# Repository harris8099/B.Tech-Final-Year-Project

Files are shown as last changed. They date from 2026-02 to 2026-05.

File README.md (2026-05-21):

# ESP32 Smart Motor Monitor — PCB Design

> KiCad schematic and PCB layout for an ESP32-based industrial motor monitoring and protection system.

---

## Quick Links

| Resource | Link |
|---|---|
| 🌐 Live cloud dashboard | [motor-frontend-psi.vercel.app](https://motor-frontend-psi.vercel.app/) |
| 🖥️ ESP32 local website (demo) | [harris8099.github.io/Motor-Website](https://harris8099.github.io/Motor-Website/index.html) |
| 📦 ESP32 firmware (this repo) | [github.com/harris8099/Final-Year-Project](https://github.com/harris8099/Final-Year-Project) |
| 🎓 PCB schematic and layout | [github.com/harris8099/B.Tech-Final-Year-Project](https://github.com/harris8099/B.Tech-Final-Year-Project) |
| 🖼️ Frontend repository | [github.com/harris8099/Motor-frontend](https://github.com/harris8099/Motor-frontend) |
| ⚙️ Backend repository | [github.com/harris8099/Motor-backend](https://github.com/harris8099/Motor-backend) |
| 📐 Project diagrams & architecture | [github.com/harris8099/Motor-project-Diagram](https://github.com/harris8099/Motor-project-Diagram) |
| 📱 Alternative Bluetooth approach | [harris8099.github.io/Bluetooth-Motor-app](https://harris8099.github.io/Bluetooth-Motor-app/) |

---

## Schematic Overview

Motor Connector Pinout
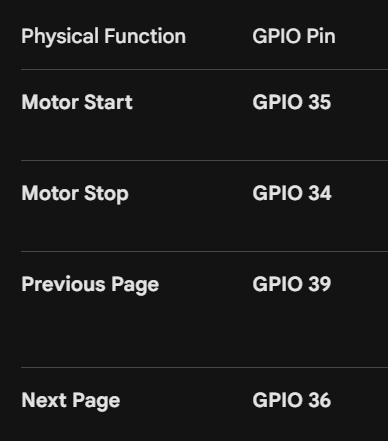
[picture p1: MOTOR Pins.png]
Motor Connector Pinout


ADXL345 Sensitivity Reference
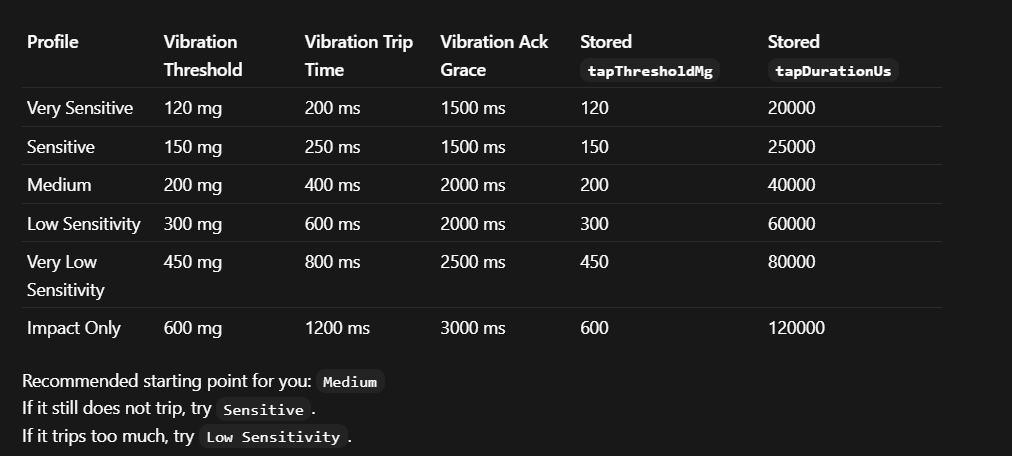
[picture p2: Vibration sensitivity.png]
ADXL345 Sensitivity


## Project Files

| File | Description |
|---|---|
| `ESP32_Smart_Motor_Project.kicad_sch` | Main schematic |
| `overall.kicad_sch` | Top-level/hierarchical schematic |
| `ESP32_Smart_Motor_Project.kicad_pcb` | PCB layout |
| `ESP32_Smart_Motor_Project.kicad_pro` | KiCad project file |
| `Symbol_Lib.kicad_sym` | Custom component symbol library |
| `sch.pdf` | Schematic PDF export |
| `Components_Links.xlsx` | Full BOM with supplier links |
| `ESP32.jpg` | ESP32 module reference image |
| `MOTOR Pins.png` | Motor connector pinout reference |
| `Vibration sensitivity.png` | ADXL345 sensitivity reference |
| `pcbway_production/` | Gerber files for PCB fabrication (PCBWay) |
| `plots/` | Schematic and layout plot exports |
| `Datasheet/` | Component datasheets |

---

## Schematic Overview

The schematic is divided into functional blocks:

### 1. Microcontroller — ESP32-WROOM-32
- Dual-core Xtensa LX6 @ 240 MHz
- 4MB Flash, 520KB SRAM
- On-board Wi-Fi 802.11 b/g/n
- USB-to-UART via CP2102/CH340 for programming and debug
- 3.3V operation with on-board LDO

### 2. Power Supply
- Input: 5V DC from external adapter or USB
- ESP32 powered via 3.3V LDO (AMS1117-3.3 or equivalent)
- Decoupling capacitors on all supply rails (100nF ceramic + 10µF electrolytic)
- Separate power domains for analog sensors and digital logic

### 3. PZEM-004T v3.0 — Power Measurement
- Interface: UART2 (TX → GPIO17, RX → GPIO16)
- Measures: Voltage (80–260V AC), Current (0–100A), Active Power, Energy (kWh), Frequency, Power Factor
- CT (current transformer) clamp around motor live wire
- Isolated from ESP32 logic via UART optocoupler or direct UART (module has internal isolation)
- Baud rate: 9600, 8N1

### 4. DS18B20 — Temperature Sensor
- Interface: 1-Wire (single GPIO)
- 4.7kΩ pull-up resistor on data line to 3.3V (**required**)
- Measures motor winding temperature: –55°C to +125°C, ±0.5°C accuracy
- Waterproof probe variant recommended for motor surface mounting

### 5. ADXL345 — Vibration / Acceleration Sensor
- Interface: I2C (SDA, SCL)
- I2C address: 0x53 (SDO pulled low) or 0x1D (SDO high)
- 4.7kΩ pull-up resistors on SDA and SCL lines
- Range: ±16g, Resolution: 3.9mg/LSB at full range
- Tap detection configured via firmware (threshold, duration, axes)
- Decoupling: 100nF on VCC pin

### 6. Hall Effect Sensor — RPM Measurement
- Interface: GPIO (interrupt-driven)
- GPIO5 configured as input with interrupt on rising edge
- Magnet mounted on motor shaft; sensor detects each revolution
- Pull-up resistor on signal line
- 100nF ceramic capacitor from signal to GND for EMI suppression

### 7. Relay Module — Motor Contactor
- Interface: GPIO (active-low)
- Drives motor contactor coil via relay
- Flyback diode (1N4007) across relay coil for back-EMF protection
- Optocoupler isolation between ESP32 logic and relay coil circuit
- LED indicator for relay state

### 8. Buzzer — Fault Alert
- Interface: GPIO (PWM capable)
- Active buzzer driven via NPN transistor (BC547 or 2N2222)
- 1kΩ base resistor, 10kΩ pull-down to prevent ghost triggering at boot
- Sounds on fault latch

### 9. TFT Display
- Interface: SPI
- CS, DC, RST, BLK connected to dedicated GPIOs
- Backlight PWM dimming capable
- Displays real-time sensor values and fault status locally

---

## Pin Assignment

| GPIO | Function | Direction | Notes |
|---|---|---|---|
| GPIO5 | Hall sensor | Input (IRQ) | 100nF cap to GND |
| GPIO16 | PZEM004T RX | Input | UART2 |
| GPIO17 | PZEM004T TX | Output | UART2 |
| GPIO21 | I2C SDA | Bidirectional | 4.7kΩ pull-up |
| GPIO22 | I2C SCL | Output | 4.7kΩ pull-up |
| GPIO26 | Relay | Output | Active-low |
| GPIO27 | Buzzer | Output | Via NPN transistor |
| 1-Wire GPIO | DS18B20 | Bidirectional | 4.7kΩ pull-up |
| SPI GPIOs | TFT Display | Output | CS/DC/RST/BLK |
| GPIO36 | TFT Button | Input | menu_next (ADC capable) |
| EN / IO0 | Boot control | — | Boot strapping pins |

---

## PCB Design Notes

### Layer Stack
- **2-layer PCB** (standard FR4, 1.6mm thickness)
- Top layer: signal routing + components
- Bottom layer: ground plane + power traces

### Design Rules
- Minimum trace width: 0.25mm (signal), 1.0mm (power), 2.0mm (5V/relay)
- Minimum clearance: 0.2mm
- Via drill: 0.8mm, via pad: 1.6mm
- Board outline: defined in Edge.Cuts layer

### Layout Guidelines Applied
- ESP32 module antenna area kept clear of copper pours and traces
- PZEM UART traces kept short and away from relay switching traces
- I2C pull-up resistors placed close to SDA/SCL pins
- DS18B20 pull-up resistor placed close to connector
- Relay and motor-side traces physically separated from ESP32 signal area
- Decoupling capacitors placed as close as possible to IC power pins
- Ground plane on bottom layer with stitching vias

### Production Files (pcbway_production/)
Standard Gerber outputs for PCBWay fabrication:
- `*.GTL` — Top copper
- `*.GBL` — Bottom copper
- `*.GTS` — Top solder mask
- `*.GBS` — Bottom solder mask
- `*.GTO` — Top silkscreen
- `*.GBO` — Bottom silkscreen
- `*.GKO` — Board outline
- `*.DRL` — Drill file (Excellon)

---

## Bill of Materials (BOM)

Full BOM with supplier links is in `Components_Links.xlsx`. Key components:

| Ref | Component | Value / Part | Package |
|---|---|---|---|
| U1 | ESP32-WROOM-32 | ESP32-WROOM-32D | Module |
| U2 | PZEM-004T | v3.0 | Module |
| U3 | ADXL345 | ADXL345BCCZ | LGA-14 |
| U4 | DS18B20 | DS18B20 | TO-92 / Probe |
| U5 | Voltage Regulator | AMS1117-3.3 | SOT-223 |
| Q1 | NPN Transistor | BC547 / 2N2222 | TO-92 |
| RL1 | Relay | 5V SPDT 10A | Through-hole |
| D1 | Flyback Diode | 1N4007 | DO-41 |
| R1 | DS18B20 Pull-up | 4.7kΩ | 0402 |
| R2, R3 | I2C Pull-up | 4.7kΩ | 0402 |
| R4 | Buzzer Base | 1kΩ | 0402 |
| R5 | Buzzer Pull-down | 10kΩ | 0402 |
| R6 | Hall Pull-up | 10kΩ | 0402 |
| C1–C5 | Decoupling | 100nF | 0402 |
| C6, C7 | Bulk Decoupling | 10µF | 0805 |
| BZ1 | Buzzer | Active 5V | Through-hole |
| J1 | Motor Connector | Screw terminal 3P | 5.08mm pitch |
| J2 | PZEM Connector | JST/Screw 4P | — |
| J3 | TFT Connector | Pin header 8P | 2.54mm |
| J4 | USB / Power | Micro-USB / DC jack | — |
| HALL1 | Hall Sensor | SS49E / A3144 | TO-92 |
| TFT1 | TFT Display | ST7789 / ILI9341 | Module |

---

## Schematic PDF

See [`sch.pdf`](sch.pdf) for the full schematic with all net labels, component values, and reference designators.

---

## Tools Used

| Tool | Version | Purpose |
|---|---|---|
| KiCad | 7.x / 8.x | Schematic capture + PCB layout |
| PCBWay | — | PCB fabrication |
| KiCad PDF Plotter | — | `sch.pdf` export |

---

## Related Repositories

| Repository | Description |
|---|---|
| [Final-Year-Project](https://github.com/harris8099/Final-Year-Project) | ESP32 firmware (ESP-IDF) |
| [Motor-frontend](https://github.com/harris8099/Motor-frontend) | React cloud dashboard |
| [Motor-backend](https://github.com/harris8099/Motor-backend) | FastAPI + PostgreSQL backend |
| [Motor-project-Diagram](https://github.com/harris8099/Motor-project-Diagram) | System architecture diagrams |

## Live Deployments

| Deployment | URL |
|---|---|
| Cloud dashboard | https://motor-frontend-psi.vercel.app/ |
| ESP32 local website demo | https://harris8099.github.io/Motor-Website/index.html |

---

## Author

**Harshil Suthar**

[LinkedIn](https://www.linkedin.com/in/harshil-suthar-942307249/) · [GitHub](https://github.com/harris8099) · [Portfolio](https://harris8099.github.io/Portfolio-2.0/)

---

*Public Domain (CC0). No warranty expressed or implied.*

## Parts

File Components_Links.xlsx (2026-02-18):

Name | Links | Datasheet
PZEM-004T | https://robocraze.com/products/peacefair-pzem-004t-110v-220v-100a-smart-energy-meter?variant=47564134351072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 | https://robu.in/wp-content/uploads/2018/03/Peacefair-PZEM-004T-AC-Multi-function-Electric-Energy-Metering-Power-Monitor-1.pdf
Relay | https://robu.in/product/1-channel-isolated-5v-relay-module-opto-coupler-for-arduino-pic-avr-dsp-arm/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
DS18B20 | https://robu.in/product/ds18b20-water-proof-temperature-probe-black-1m-2/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
ADXL345 | https://robu.in/product/adxl345-tripple-axis-accelerometer-board/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
Hall sensor | https://robu.in/product/hall-magnetic-sensor-module/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
TFT display | https://robu.in/product/62060/

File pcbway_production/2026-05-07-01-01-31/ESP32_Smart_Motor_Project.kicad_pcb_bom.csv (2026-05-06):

Designator | Quantity | Value | Footprint | Package | MPN | DNP | Mount_Type | Description | KiLib_Generator
A1 | 1 | ~ | ADXL345 |  |  |  | smt
B1 | 1 | ~ | Buzzer_12x9.5RM7.6 |  |  |  | tht
D1 | 1 | ~ | TFT_display |  |  |  | smt
H1 | 1 | ~ | Hall_sensor |  |  |  | smt
L1 | 1 | ~ | Logic_convertor |  |  |  | smt
M3 | 1 | ~ | ESP32 |  |  |  | smt
P1 | 1 | ~ | PZEM_004T |  |  |  | smt
P2 | 1 | ~ | Power_supply |  |  |  | smt
Q1 | 1 | IRLZ34N | TO-220-3_Vertical |  |  |  | tht | 30A Id, 55V Vds, 35mOhm Rds, N-Channel HEXFET Power MOSFET, TO-220AB | package/TO_SOT/THT
R1, R4, R6, R7, R8 | 5 | 10K | R_Axial_DIN0207_L6.3mm_D2.5mm_P7.62mm_Horizontal |  |  |  | tht | Resistor | resistor/THT
R2 | 1 | 4.7K | R_Axial_DIN0207_L6.3mm_D2.5mm_P7.62mm_Horizontal |  |  |  | tht | Resistor | resistor/THT
R3 | 1 | 100ohm | R_Axial_DIN0207_L6.3mm_D2.5mm_P7.62mm_Horizontal |  |  |  | tht | Resistor | resistor/THT
R5 | 1 | ~ | Relay |  |  |  | smt
SW1, SW2, SW3, SW4 | 4 | SW_Push | PinSocket_1x02_P2.54mm_Vertical |  |  |  | tht | Push button switch, generic, two pins | connector/pin_header_socket
T1 | 1 | ~ | DS18B20 |  |  |  | smt

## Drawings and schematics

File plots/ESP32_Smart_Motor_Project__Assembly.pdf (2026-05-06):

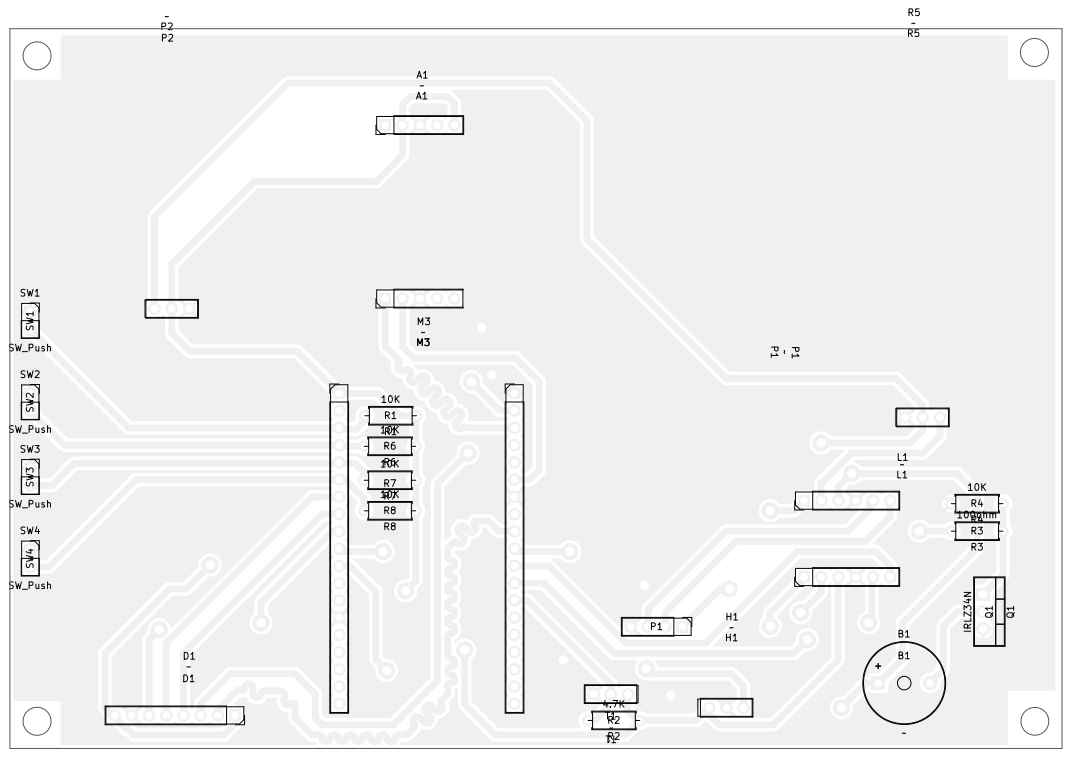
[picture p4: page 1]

Board2Pdf: Black And White TOP - Page 1/8

HARSHIL SUTHAR
Sheet: Black And White TOP
File: ESP32_Smart_Motor_Project.kicad_pcb
Title:
KiCad E.D.A. 10.0.1

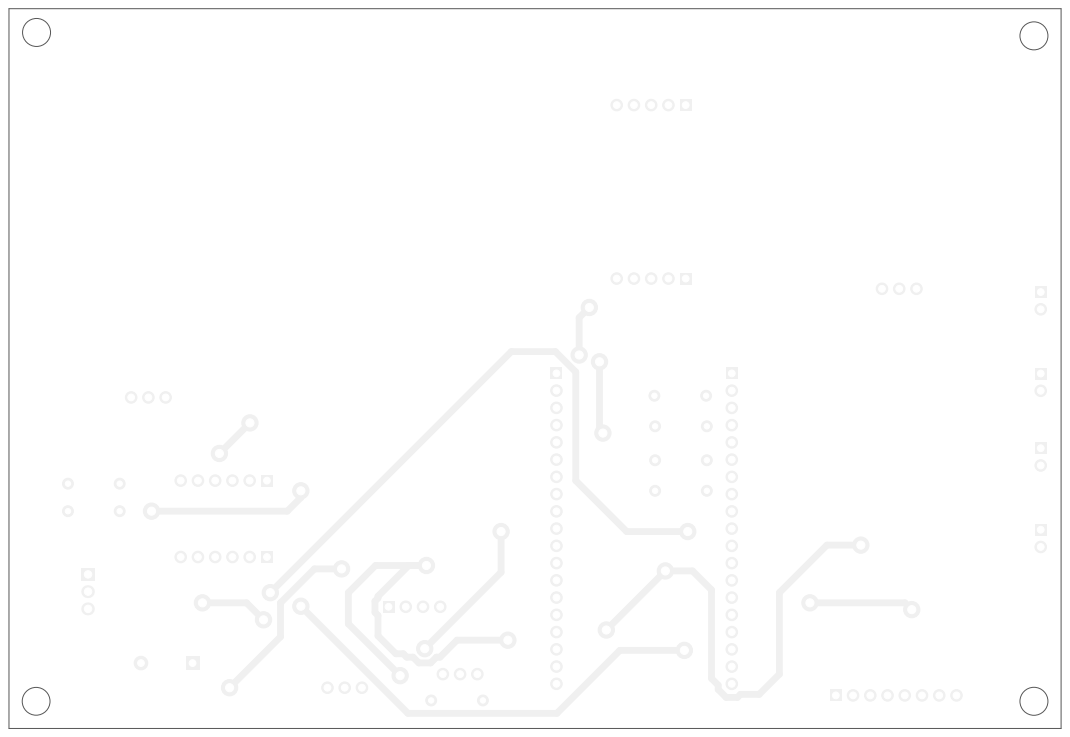
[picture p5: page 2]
D Date: 2026-05-07

Board2Pdf: Black And White BOT - Page 2/8

HARSHIL SUTHAR
Sheet: Black And White BOT
File: ESP32_Smart_Motor_Project.kicad_pcb
Title:

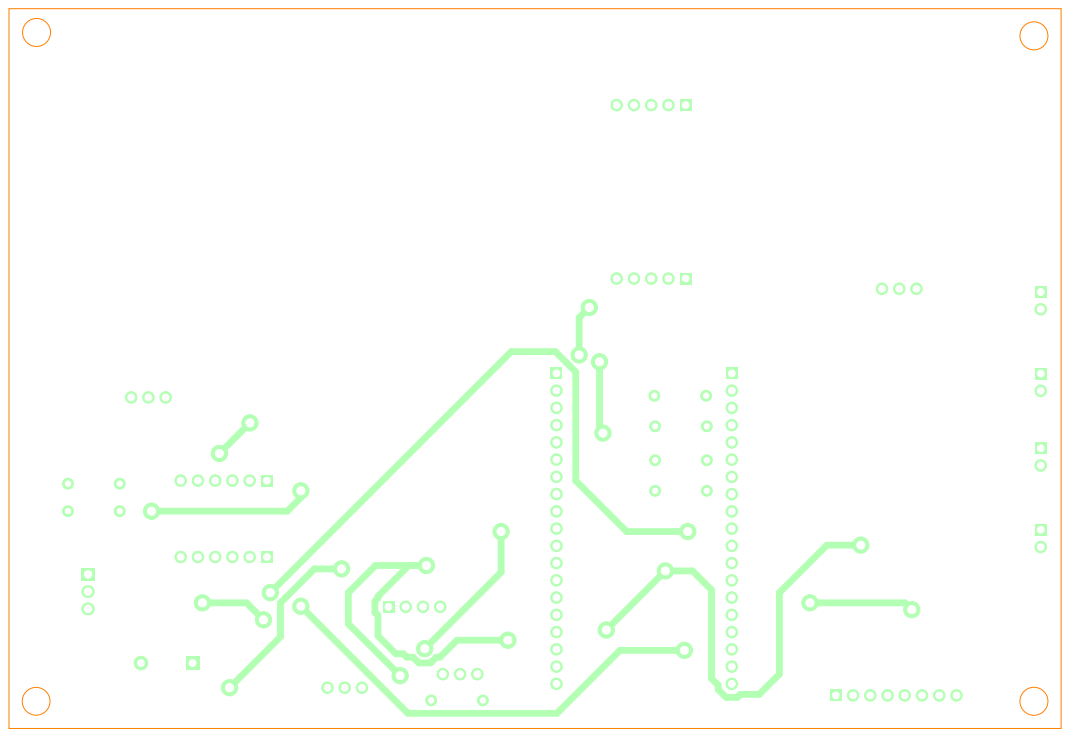
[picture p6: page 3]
D Date: 2026-05-07

Board2Pdf: Colored BOT - Page 3/8

HARSHIL SUTHAR
Sheet: Colored BOT
File: ESP32_Smart_Motor_Project.kicad_pcb
Title:

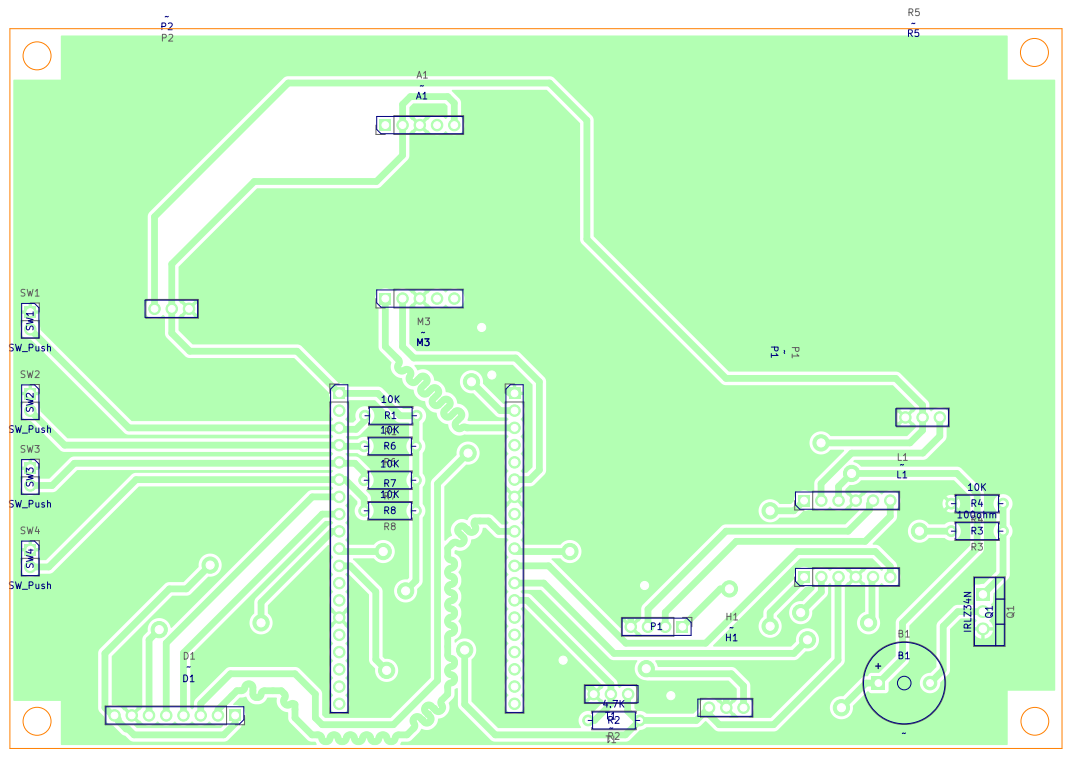
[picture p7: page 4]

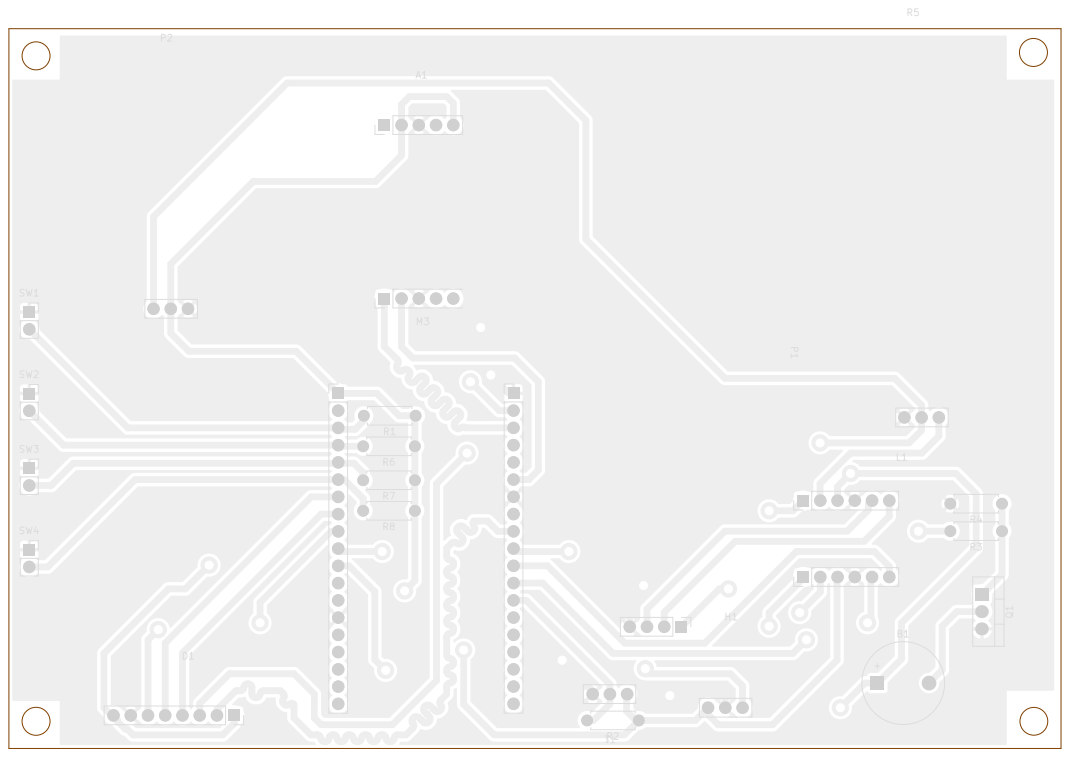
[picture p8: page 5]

Board2Pdf: Light Colors PCB Fabrication TOP - Page 5/8

HARSHIL SUTHAR
Sheet: Light Colors PCB Fabrication TOP
File: ESP32_Smart_Motor_Project.kicad_pcb
Title:

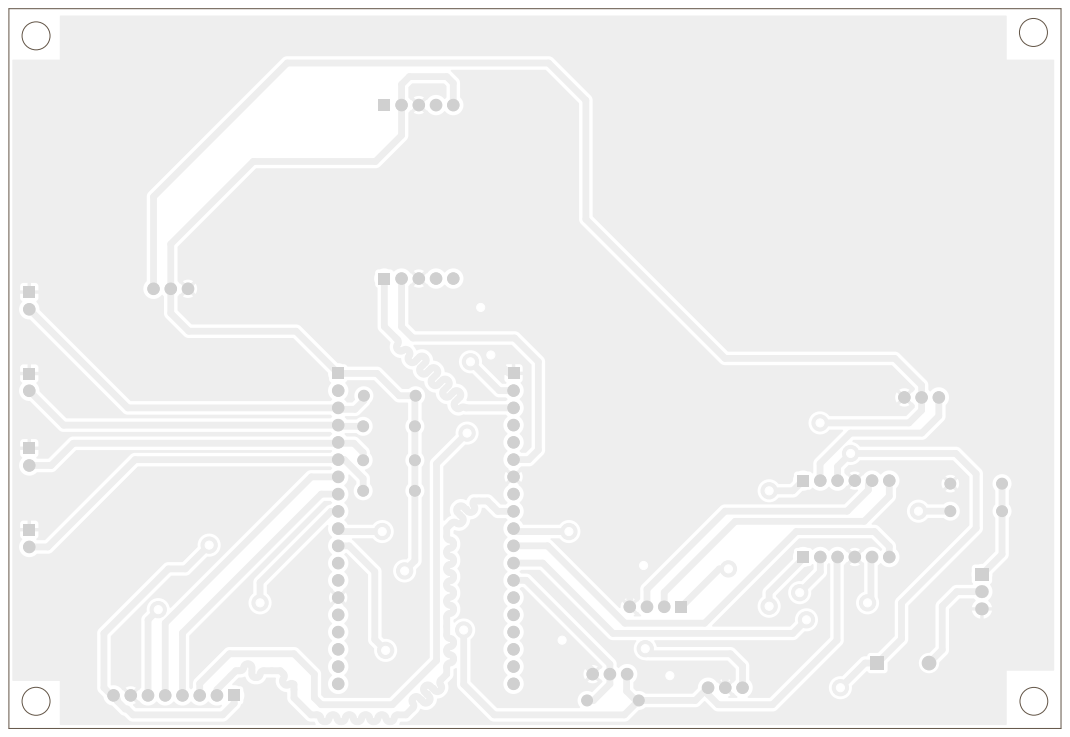
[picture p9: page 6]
D Date: 2026-05-07

Board2Pdf: Light Colors PCB Paste TOP - Page 6/8

HARSHIL SUTHAR
Sheet: Light Colors PCB Paste TOP
File: ESP32_Smart_Motor_Project.kicad_pcb
Title:

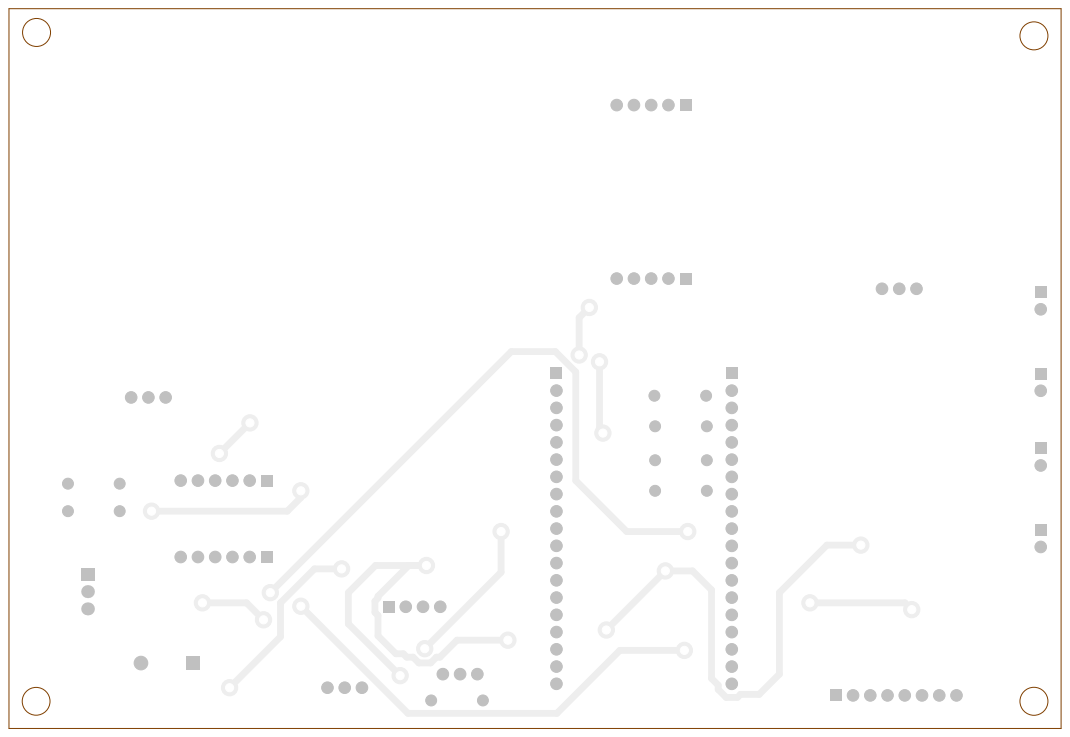
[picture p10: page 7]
D Date: 2026-05-07

Board2Pdf: Light Colors Placement BOT - Page 7/8

HARSHIL SUTHAR
Sheet: Light Colors Placement BOT
File: ESP32_Smart_Motor_Project.kicad_pcb
Title:

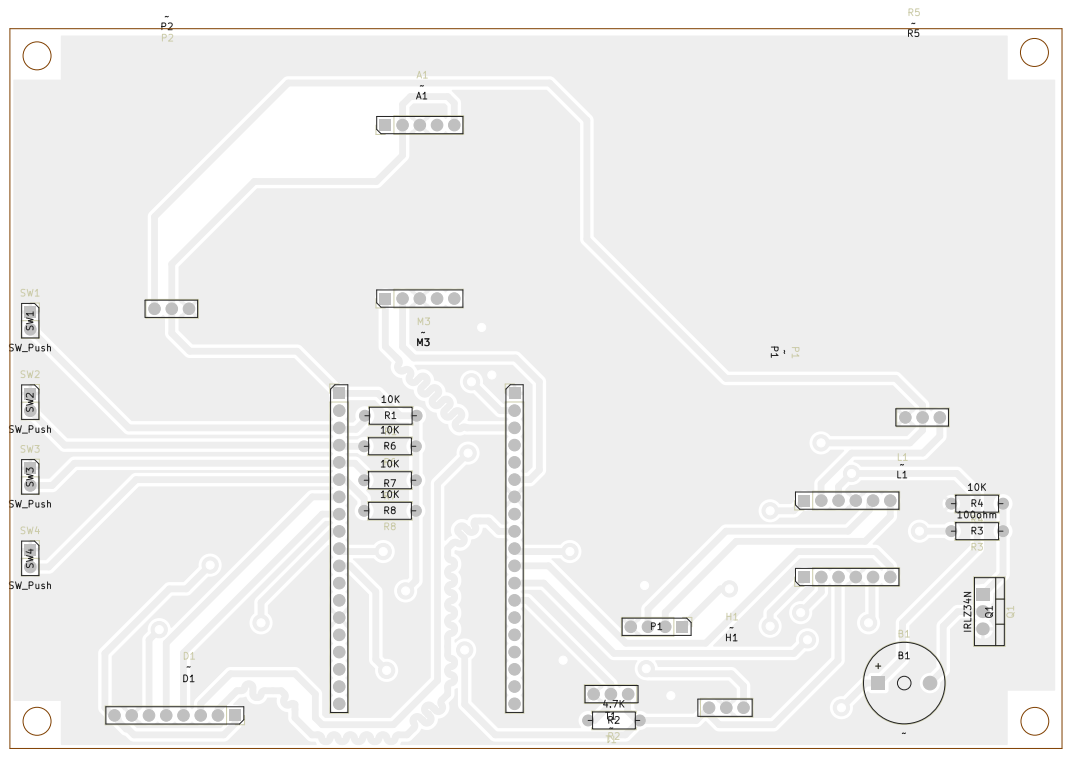
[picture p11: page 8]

Board2Pdf: Light Colors Placement TOP - Page 8/8

HARSHIL SUTHAR
Sheet: Light Colors Placement TOP
File: ESP32_Smart_Motor_Project.kicad_pcb
Title:

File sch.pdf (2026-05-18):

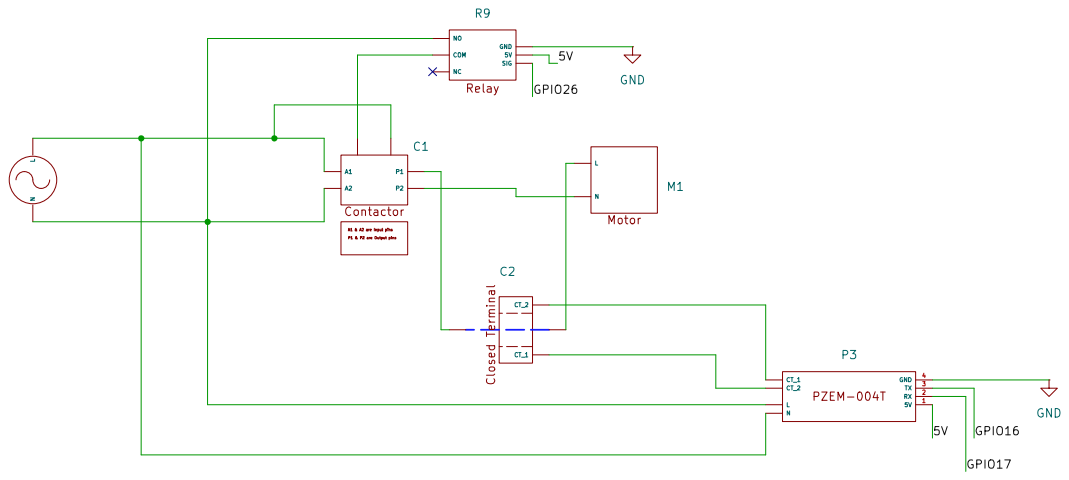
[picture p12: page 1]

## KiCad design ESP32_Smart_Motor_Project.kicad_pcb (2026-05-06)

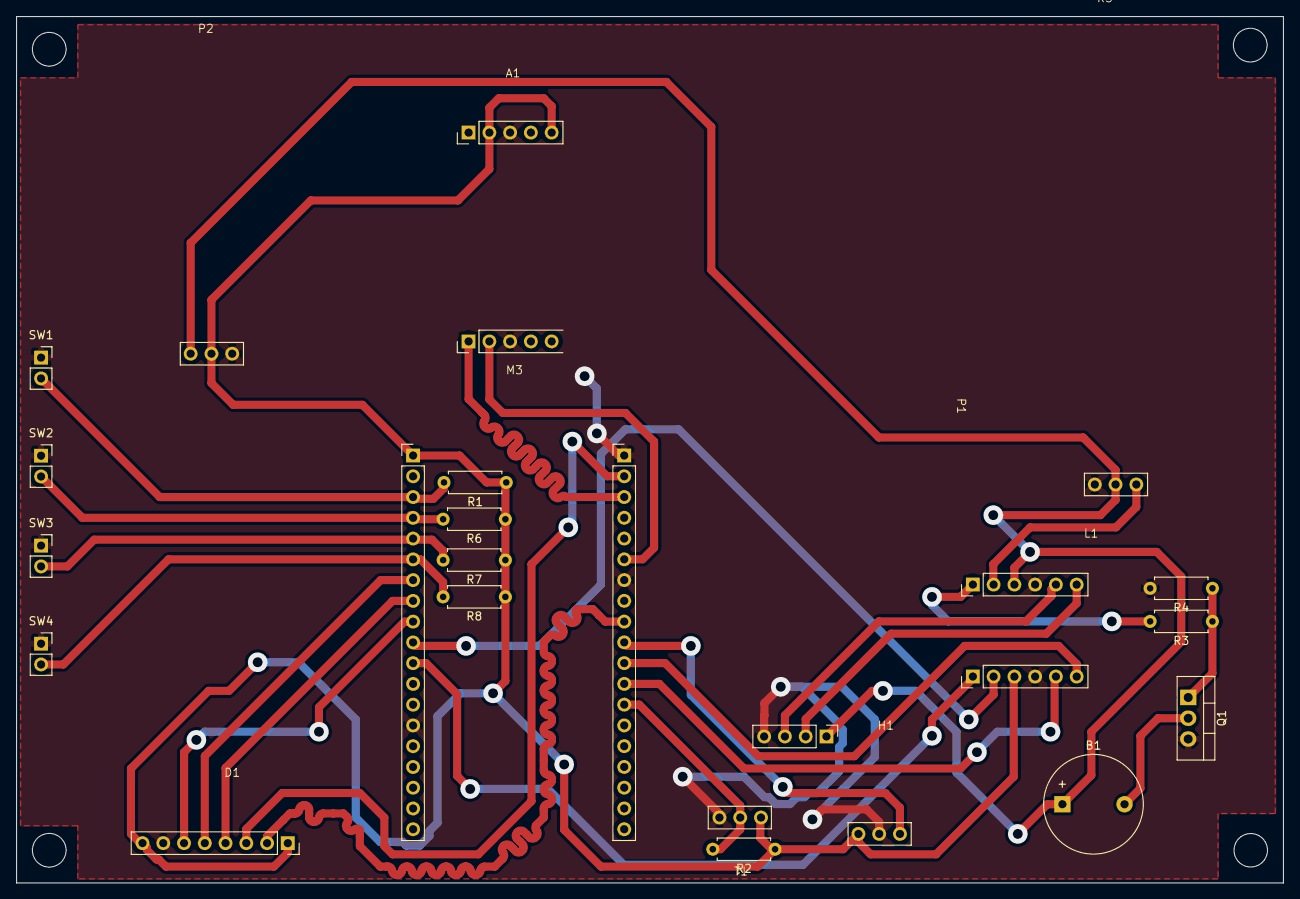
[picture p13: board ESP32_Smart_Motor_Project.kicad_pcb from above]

Board: 2 copper layers, 155.0 x 106.0 mm, 22 parts (0 on the bottom side), 26 nets.

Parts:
A1: ADXL345
B1: Buzzer_12x9.5RM7.6
D1: TFT_display
H1: Hall_sensor
L1: Logic_convertor
M3: ESP32
P1: PZEM_004T
P2: Power_supply
Q1: IRLZ34N; TO-220-3_Vertical
R1, R4, R6, R7, R8: 10K; R_Axial_DIN0207_L6.3mm_D2.5mm_P7.62mm_Horizontal
R2: 4.7K; R_Axial_DIN0207_L6.3mm_D2.5mm_P7.62mm_Horizontal
R3: 100ohm; R_Axial_DIN0207_L6.3mm_D2.5mm_P7.62mm_Horizontal
R5: Relay
SW1, SW2, SW3, SW4: SW_Push; PinSocket_1x02_P2.54mm_Vertical
T1: DS18B20

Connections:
/3V3: A1.2 (3V3), A1.5 (CS), D1.1 (LED), D1.8 (3.3V), H1.1 (3V3), L1.9 (LV), M3.20 (3.3V), P2.2 (3V3), R1.1, R2.1, R6.1, R7.1, R8.1, T1.1 (3V3)
/5V: B1.1 (SIG), L1.3 (HV), P1.1 (5V), P2.1 (5V), R5.2 (5V)
/GND: A1.3 (GND), A1.8 (SDO), D1.7 (GND), H1.2 (GND), L1.4 (GND), L1.10 (GND), M3.1 (GND), M3.7 (GND), M3.33 (GND), P1.4 (GND), P2.3 (GND), Q1.3 (S), R4.2, R5.1 (GND), SW1.1, SW2.1, SW3.1, SW4.1, T1.3 (GND)
/GPIO4: M3.13 (GPIO4), R2.2, T1.2 (SIG)
/GPIO5: H1.3 (DO), M3.10 (GPIO5)
/GPIO16: L1.11 (LV3), M3.12 (GPIO16)
/GPIO17: L1.12 (LV4), M3.11 (GPIO17)
/GPIO18: D1.2 (SCK), M3.9 (GPIO18)
/GPIO21: A1.7 (SDA), M3.6 (GPIO21)
/GPIO22: A1.6 (SCL), M3.3 (GPIO22)
/GPIO23: D1.3 (SDA), M3.2 (GPIO23)
/GPIO25: D1.6 (CS), M3.28 (GPIO25)
/GPIO26: L1.8 (LV2), M3.29 (GPIO26)
/GPIO27: L1.7 (LV1), M3.30 (GPIO27)
/GPIO32: D1.5 (RESET), M3.26 (GPIO32)
/GPIO33: D1.4 (AO), M3.27 (GPIO33)
/GPIO34: M3.24 (GPIO34), R7.2, SW3.2
/GPIO35: M3.25 (GPIO35), R8.2, SW4.2
/GPIO36: M3.22 (GPIO36), R1.2, SW1.2
/GPIO39: M3.23 (GPIO39), R6.2, SW2.2
/HV1: L1.1 (HV1), R3.2
unnamed: B1.2 (GND), Q1.2 (D)
unnamed: L1.2 (HV2), R5.3 (SIG)
unnamed: L1.5 (HV3), P1.3 (TX)
unnamed: L1.6 (HV4), P1.2 (RX)
unnamed: Q1.1 (G), R3.1, R4.1

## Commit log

2026-04-15 pcb design for smart motor project
    [ESP32_Smart_Motor_Project-CuBottom.gbr, ESP32_Smart_Motor_Project-CuTop.gbr, ESP32_Smart_Motor_Project-EdgeCuts.gbr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]
2026-04-17 minor changes
    [ESP32_Smart_Motor_Project-CuBottom.gbr, ESP32_Smart_Motor_Project-CuTop.gbr, ESP32_Smart_Motor_Project-EdgeCuts.gbr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]
2026-04-21 make changes to board size
    [ESP32_Smart_Motor_Project.kicad_pcb, ESP32_Smart_Motor_Project.kicad_sch]
2026-05-16 Added new sch
    [ESP32_Smart_Motor_Project.kicad_sch, overall.kicad_sch]
2026-05-21 Revise README for ESP32 Smart Motor Monitor project
    Updated project title and added detailed project overview, quick links, schematic overview, project files, schematic details, PCB design notes, bill of materials, tools used, related repositories, li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
